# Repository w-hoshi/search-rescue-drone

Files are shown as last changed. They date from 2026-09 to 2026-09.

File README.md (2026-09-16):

# Search and Rescue Drone: LiDAR SLAM and Person Detection Payload

A low-cost drone payload for mapping in GPS-denied environments. Runs 2D LiDAR SLAM and YOLOv8 person detection onboard a Raspberry Pi 5. Senior design project, ME 461, Boston University.

**[Demo 1 — mapping during flight](https://youtu.be/b8vK8jm33Qs)** — 2D occupancy grid building in real time (bottom right) as the drone flies an indoor corridor.

**[Demo 2 — person detection onboard](https://youtu.be/7SwgwFV0m5k)** — YOLOv8 running on the Pi 5 with the flight camera, drone held at a fixed height. This is a subsystem check that detection ran onboard at usable frame rate, not a demonstration of detection placed onto the map. The two demos are separate systems; see below.

Commercial SLAM-capable rescue drones start around $15k. The goal was to see how much of the core capability, indoor mapping without GPS plus onboard person detection, could be built from off-the-shelf parts and open-source ROS 2 packages under a $400 budget. The payload bolts onto an existing airframe and does not fly the drone.

| | |
|---|---|
| Compute | Raspberry Pi 5 |
| Mapping | `slam_toolbox`, 2D occupancy grid |
| Odometry | `rf2o_laser_odometry` (laser scan matching) |
| Detection | YOLOv8 via `yolo_ros` |
| Payload weight | 0.76 kg |
| Runtime | 31 min |
| Payload cost | ~$346 |

## Architecture

```
DFR0315 2D LiDAR ──> laser_filters ──> rf2o_laser_odometry ──> /odom
                            │                                    │
                            └────────────> slam_toolbox <─────────┘
                                                │
                                                ├──> /map (occupancy grid)
                                                └──> tf: map -> odom -> base_link

ELP USB camera ──> yolo_ros (YOLOv8) ──> /yolo/detections ──> [person_mapper]
```

Two things about that diagram:

**Localization is LiDAR-only.** Odometry comes from scan matching in `rf2o_laser_odometry`. The MPU-6050 IMU is wired and readable but is not in the estimation loop; see below for what we tried. The camera is monocular, so there is no visual SLAM and no depth.

**Detection and mapping ran as separate subsystems.** Both halves work on their own but they were never run together. Bounding boxes were never placed onto the occupancy grid. The node that would do that, `person_mapper`, is in this repo and was never run. The bracket around it in the diagram marks that boundary.

## Repository layout

```
src/
├── rcdrone_slam/          SLAM launch + configs (slam_toolbox, rf2o, laser filter)
├── offboard_control/      Basic PX4 offboard flight tests
└── person_mapper/         Detection-to-map projection (written, never validated)
hardware/
├── cad/                   Payload housing, STEP + STL + native
└── images/                Build and assembly photos

```

Mechanical design notes, constraints, and what I would change are in [`hardware/README.md`](hardware/README.md).

## Build and run

The repo root is a colcon workspace. Four third-party packages are not vendored and need cloning into `src/` first: `laser_filters`, `rf2o_laser_odometry`, `ros2_mpu6050_driver`, `yolo_ros`.

```bash
git clone https://github.com/w-hoshi/search-rescue-drone.git
cd search-rescue-drone/src
# clone the four dependencies here
cd ..
rosdep install --from-paths src --ignore-src -r -y
colcon build --symlink-install
source install/setup.bash
ros2 launch rcdrone_slam mapping.launch.py
```

YOLO weights are not in the repo. We ran `yolov8n`; `yolov8m` was too slow on the Pi 5 to be useful at frame rate. Visualize on a ground station rather than on the Pi, since RViz competes with YOLO for CPU.

## Results

With limited time and a system that had to be built, wired, printed, and integrated before it could be tested at all, the priority was getting a working pipeline in the air rather than characterizing how well it performed. What follows is a qualitative account. We did attempt quantitative mapping accuracy against tape-measured ground truth, but the measurement procedure was not rigorous enough for the numbers to mean much, so they are left out here.

**Mapping worked.** Flying an indoor corridor, `slam_toolbox` produced an occupancy grid with recognizable structure: straight wall runs, corner junctions, and correct hallway topology matching the real building. It built continuously during flight rather than needing a post-processing pass. Visible in demo 1.

The map also contains phantom wall segments where the corridor has windows. Glass either passes the beam or reflects it off-axis, so range readings there are inconsistent and `slam_toolbox` writes structure that isn't real. Also visible in the video.

The drone's legs sit inside the LiDAR's scan plane, so laser_filters drops all returns under a minimum range threshold to keep them out of the map. The cost is a set of blind wedges that move with the drone, visible in demo 1 as small gaps in the occupancy grid near the vehicle. In practice they close almost immediately: as the drone advances, cells that were occluded on one frame get scanned from a new position on the next, and slam_toolbox fills them in. The gaps only persist if the drone holds still.

**Detection ran onboard.** YOLOv8n inference on the Pi 5, using the same ELP camera and mount that flew, produced stable person detections at a usable rate with the drone held at a fixed height (demo 2). This established that the compute and camera choices were adequate for the detection half of the system. It does not establish detection performance in flight, where vibration, motion blur, and changing viewing angle all work against it, and we never tested that.

**The drone was overweight.** Battery, payload, and electronics put the F450 near its practical limit, and handling suffered. This shortened useful test runs and limited how the system could be flown.

**Autonomy was dropped.** `offboard_control` contains working PX4 offboard primitives (`takeoff_to_1m`, `forward_for_2s`) and nothing beyond them. Localization was not reliable enough to trust a closed-loop indoor mission, and the drone's marginal flight stability made it worse. All demo flights were manually piloted.

## Why the IMU isn't used

The original plan was to fuse the MPU-6050 with laser odometry so the two would cover each other's weaknesses.

We had some immediate problems. Even when it was sitting completely still on a bench, the IMU produced a consistent drift in one direction. The integrated estimate reported the payload translating when nothing was moving. This small constant error in the raw reading is typical and comes from integrating acceleration twice and the constant bias grows as the square of elapsed time, so a stationary system slowly accelerates off into nowhere.

**First attempt: subtract a static offset.** Hold the payload still, average the readings, treat the result as the bias, and subtract it. This helped for the first few seconds and then stopped helping. The cheap MEMS accelerometer's bias didn't stay a fixed number. It shifted with temperature, and the Pi and buck converter sitting in a sealed PETG enclosure meant temperature was increasing the whole time the system ran. On top of that, calibrating on a bench and flying under spinning props are different environments: vibration adds broadband noise the accelerometer can't separate from real motion, and once the airframe tilts, part of gravity leaks into the horizontal axes and reads as sideways acceleration.

**Second attempt: an EKF.** Fusing IMU and laser odometry in an extended Kalman filter was a suggested solution, but the filter didn't help either. An EKF weights each input by its assumed noise, so it needs realistic covariances to work, and getting those right for a vibrating MPU-6050 is its own tuning problem that we didn't have time to solve. More fundamentally, there wasn't much for the IMU to add. Scan matching against corridor walls was already giving a decent pose estimate at a reasonable rate, and injecting a noisy, biased second source made the fused output worse than the odometry alone. 

**Final Result** LiDAR-only localization through `rf2o_laser_odometry` and `slam_toolbox`. The IMU driver is still in the build and publishing, just not feeding the estimator.

In hindsight its not a suprising conclusion is that a $20 6-DOF IMU with no magnetometer, stuck to a vibrating airframe with foam tape, isn't a useful localization input in a feature-rich indoor environment where a LiDAR can see walls. It would matter more in a long featureless corridor or a smoke-filled room where scan matching has nothing to lock onto but it was never tested in either enviroments.

## person_mapper: implemented, never validated

This is the piece that would have made the system do what it claims: put detected people onto the map. It is fully written and was never run against live SLAM and detection. Never integrated into a launch file and never tested due to time constraints.

The approach, given a monocular camera and no depth sensor:

1. Take the bounding box center pixel from a detection.
2. Back-project it to a ray in the camera frame using the intrinsics.
3. Rotate the ray into the map frame, composing the fixed 25 degree camera tilt with the drone's yaw from the `map -> base_link` transform.
4. Intersect that ray with the ground plane (z = 0) for an (x, y) map coordinate. This substitutes for depth: assume the person is on the floor and altitude is known.
5. Associate against previously seen people so one person doesn't become a trail of markers.
6. Publish a cylinder marker per person for RViz.

Issues I've since identified and have not fixed, since there are no recorded rosbags to test against:

- **Marker lifetime is 3 seconds and only current-frame detections are published.** A person would vanish from the map once the drone flew past, which defeats the purpose. Needs infinite lifetime and republishing of accumulated positions.
- **The track ID check is wrong.** `Detection.id` is a string and is empty rather than absent when tracking is off, so the `is not None` test always passes and every detection collapses onto one key. The proximity fallback never runs.
- **Projecting the bbox center biases range long.** Ground-plane intersection assumes the projected pixel is where the person contacts the floor. The torso center sits above that, so estimated positions land farther out than the truth. Systematic, not noise. Should project the bottom edge of the box.
- **Roll and pitch are discarded.** The full quaternion is read but only yaw is used. A few degrees of pitch in flight moves the ground intersection substantially.
- **Altitude is a fixed parameter.** 2D LiDAR SLAM gives no useful z estimate, so altitude is hardcoded rather than measured.

Multi-view triangulation would be the better approach than a ground-plane assumption: accumulate detections of the same person from several known drone poses and triangulate. That removes the flat-floor and fixed-altitude assumptions, both of which are bad in the environments this was meant for.

## Hardware

| Component | Part | Notes |
|---|---|---|
| Compute | Raspberry Pi 5 | USB 3.0 for LiDAR and camera, I2C for IMU |
| LiDAR | DFR0315 | 360°, ~8000 samples/sec, 5.5–10 Hz |
| Camera | ELP 48MP USB | Mounted at 25° below horizontal |
| IMU | MPU-6050 | I2C, near payload center of mass |
| Power | 3S LiPo into U6223 buck converter | Regulated to 5V |
| Housing | PETG, 3D printed | CAD and photos in [`hardware/`](hardware/) |
| Airframe | HAWK'S WORK F450 | Test platform, not part of the payload |

Cylindrical PETG body with a detachable angled front face carrying the camera, a bottom cutout giving the LiDAR unobstructed 360° coverage, and a top plate bolted to the F450 arms. The 25 degree camera tilt is fixed in the print, which is what makes the camera-to-body rotation in `person_mapper` a constant.

Design constraints, the reasoning behind each of those choices, and what I would change are written up in [`hardware/README.md`](hardware/README.md).

`docs/frames_*.pdf` are `view_frames` dumps from three points in testing, showing the tf tree that was actually running.

## Team and attribution

ME 461 senior design, Boston University. Team 248: Wataru Hoshi, Justen Li, Jonathan Thea, Vincent Lin. Advised by Prof. Geiger, with Prof. Tron as technical advisor.

My work: sensor selection (LiDAR and IMU), payload housing design and 3D printing, mechanical integration and mounting, electrical assembly with Jonathan Thea, running and tuning the SLAM pipeline, the IMU drift investigation above, and the `person_mapper` node. Set up the detection node with Justen Li.

The project concluded with the course and the hardware was returned to the school, so this repo is a record of the work rather than an active project.

## License

MIT

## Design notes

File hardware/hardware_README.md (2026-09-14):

# Payload Housing: Mechanical Design

The enclosure that carries the LiDAR, camera, IMU, Pi 5, and power electronics, and attaches the assembly to an F450 airframe. Designed, printed, and integrated by me as part of the [search and rescue drone project](../README.md).

Finished payload: **0.76 kg**, PETG, cylindrical body with a detachable front face.
Designed in Solidworks

<!-- Replace these filenames with your actual uploads in hardware/images/ -->
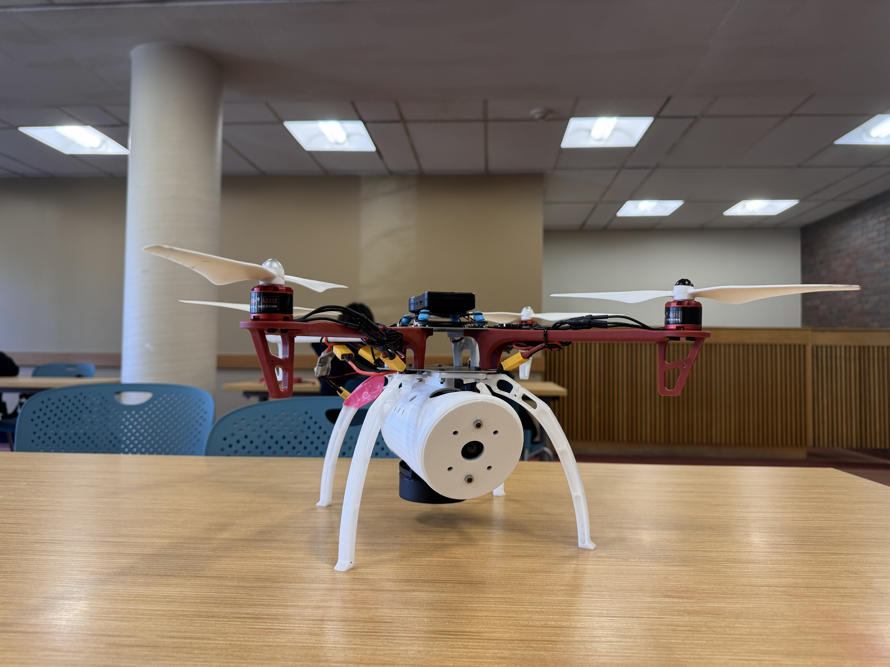
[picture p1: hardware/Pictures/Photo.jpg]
Assembled payload mounted to the F450

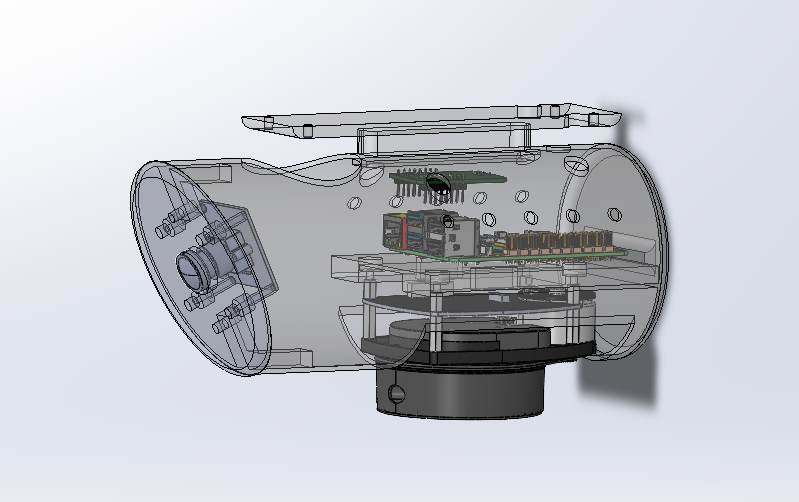
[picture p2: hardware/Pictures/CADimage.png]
Internal layout: Pi 5, buck converter, IMU


## Housing requirements

The mechanical requirements came from the sensors and the airframe:

| Constraint | Where it came from |
|---|---|
| 360° unobstructed LiDAR horizon | The DFR0315 scans a full circle, so any structure in that plane becomes a permanent artifact in every map |
| Fixed, known camera angle | `person_mapper` composes a camera-to-body rotation as a constant. If the camera can shift, that constant is wrong and every projected detection is wrong |
| IMU near the payload center of mass | Off-axis mounting turns airframe rotation into spurious linear acceleration |
| Minimum mass | The F450 was already at its practical limit with battery and electronics |
| Attach to an existing airframe | The payload mounts to an F450 I did not design and could not modify |
| Serviceable between flights | Battery swaps and payload removal had to be fast |

## Design decisions

**LiDAR mounted upside down at the bottom of the payload.** This was the best available position on two counts. It keeps the scan plane well clear of the propeller disc, and it tucks the unit under the body where it is less exposed to damage on hard landings. The drone's legs still sit inside the scan plane, which is handled in software with a minimum range filter.

**Detachable angled front face.** The 25° downward camera tilt is printed into the geometry rather than set with an adjustable bracket. A fixed angle is a known angle, and `person_mapper` depends on that. Making the face detachable kept the camera serviceable without making the angle adjustable.

**Screwed to the underside of the drone's bottom plate, with a cork damping layer in the joint.** Mounting underneath left the battery bay clear, so batteries could be swapped between flights without touching the payload. The whole unit also comes off in a few screws, which was nice since the system was constantly being reopened for debugging. The cork takes some of the airframe vibration out of the joint before it reaches the sensors.

**PETG.** More flexible and less brittle than PLA, so it deforms under crash loads instead of shattering. That toughness is also what allowed thinner walls than PLA would have survived, which mattered given how tight the mass budget was.

Power sized from measurement, not from a datasheet guess. The battery was chosen after the sensors were settled, so the load was known before the capacity was. I ran the Pi and sensors together at the compute settings we expected to fly, measured actual draw, and picked a 3S LiPo that met a 30 minute minimum endurance target, then retested once the full system was wired to confirm the estimate held. Battery voltage goes through a U6223 step down converter regulated to 5V, with every component drawing power through the Pi rather than tapping the pack separately. We were carefule since a 3S pack sits at 11.1V nominal and up to 12.6V fresh off the charger, and any of that reaching a 5V input kills the board. A switch was connected between the step down converter for easy power toggle.

**Access and vent holes.** The body has multiple openings for cable routing, airflow over the Pi and buck converter and as access holes. Internal airflow is still limited and the IMU likely ran warm, though I have no measurements to say how much that mattered.

## What I would change

**Weight was the defining constraint.** The finished payload put the F450 over its rated maximum. The answer was a larger airframe with more thrust margin, but that was outside the project budget, so the only lever left was making the payload lighter. I redesigned the housing several times to cut mass, thinning walls and removing material wherever the structure allowed. It was not enough. The LiDAR, camera, and Pi are what they are, and the battery had to be large enough for a useful flight time, so the mass of the sensing and power hardware sat above the margin no matter what the enclosure weighed. The result was persistent difficulty keeping the drone stable, shorter test flights than planned, and less data collected than the project needed.

Next time I would size the mass budget against the airframe's measured thrust margin at the start and let it drive component selection, instead of choosing sensors first and trying to recover the difference in the enclosure.

**Foam tape was not enough isolation for the IMU.** It damped some vibration bu was it was clearly inadequate under spinning props. Motor vibration coupled into the accelerometer, which cannot separate it from real acceleration. A designed isolator with a corner frequency below the prop passing frequency is what I would build next time.

**Better separation between the IMU and the heat sources.** The vent holes helped, but I would move the IMU out of the same enclosed volume as the Pi and the buck converter. Even without knowing how much heat actually contributed to the drift, keeping a temperature sensitive sensor away from the two components dissipating the most power is cheap insurance.

## Files

```
cad/
├── *.stl       Print ready, GitHub renders these in the browser
└── *.sldprt    Native SolidWorks
images/         Build and assembly photos
```

Click any STL to rotate it in the browser without downloading.

## Notes

3D printed in PETG with a BAMBU A1 printer. The hardware was returned to the school when the course ended, so this is a design record rather than a live build.

Most of the compromises above come back to the same two limits. The budget fixed the airframe, which fixed the mass ceiling, which drove several rounds of housing redesign that still could not close the gap. The schedule meant the system had to be built, wired, printed, and integrated before any of it could be tested, so problems like the vibration coupling only surfaced late, with no time left to redesign around them. A lot of what looks like a sensing or software problem in this project traces back to those two constraints.

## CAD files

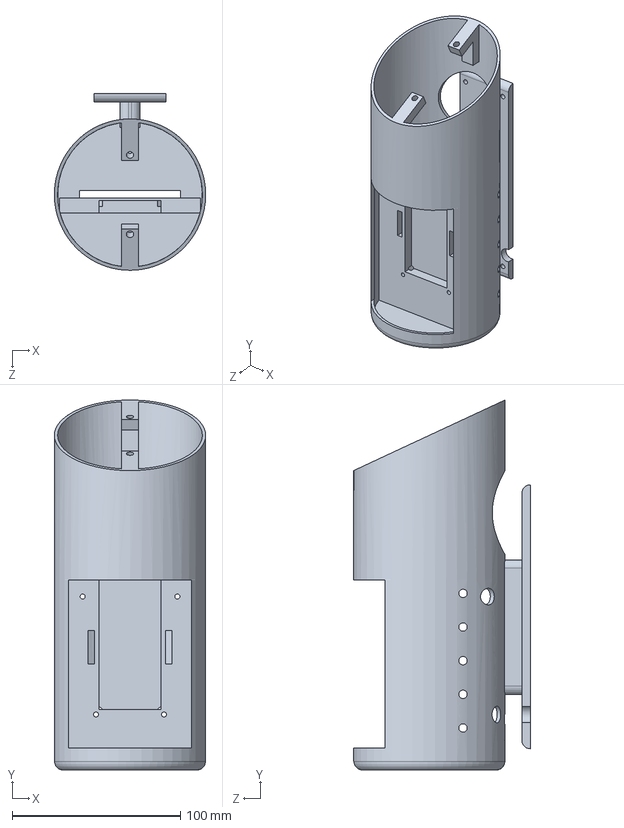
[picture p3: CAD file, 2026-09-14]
hardware/CAD/HousingCAD.SLDPRT
90.0 x 220.0 x 105.0 mm

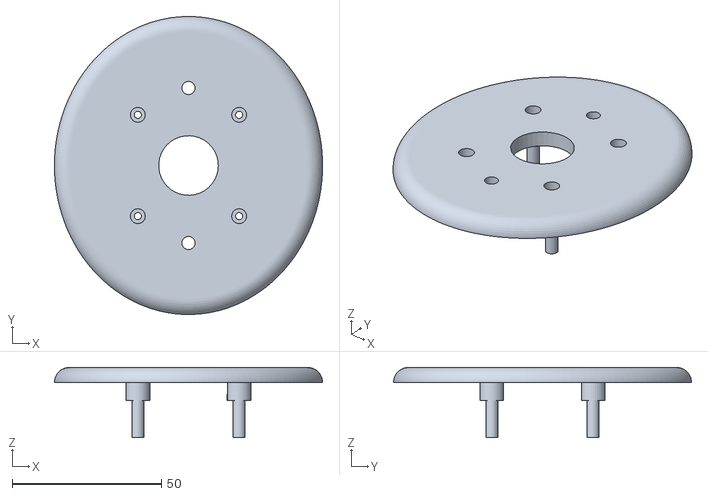
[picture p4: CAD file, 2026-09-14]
hardware/CAD/HousingLIDCAD.STL
90.0 x 100.0 x 23.5

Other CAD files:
hardware/CAD/HousingCAD.STL
